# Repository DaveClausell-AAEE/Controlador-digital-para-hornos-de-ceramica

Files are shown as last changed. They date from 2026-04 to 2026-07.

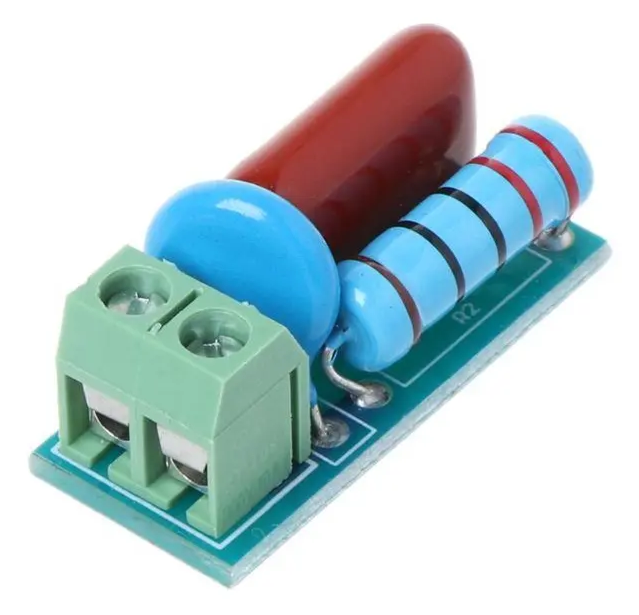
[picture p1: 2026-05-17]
hardware/snubber/snubber2.png

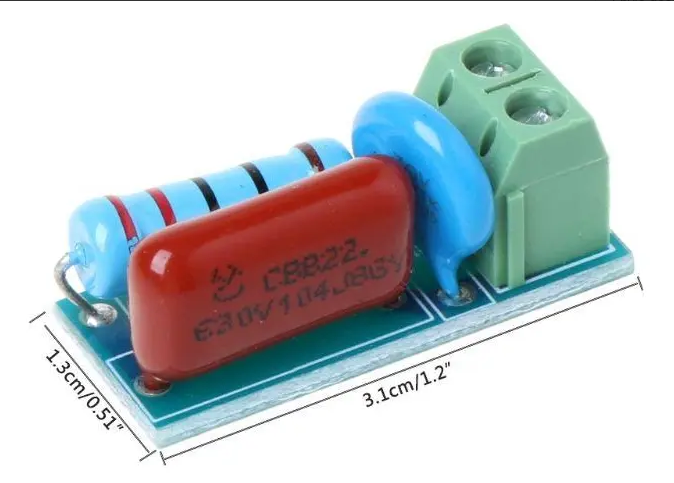
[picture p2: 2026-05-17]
hardware/snubber/snubber1.png

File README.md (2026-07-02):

# Controlador Digital para Horno de Cerámica (ESP32) V13.0 Industrial

Este proyecto es un controlador de temperatura profesional para hornos de cerámica basado en el microcontrolador **ESP32**. La versión 13.0 introduce una arquitectura de grado industrial con buses de datos separados para máxima estabilidad y feedback visual remoto.

## 🚀 Características Principales (V13.0 Industrial)
- **Arquitectura SPI Dual:** Separación física de buses (HSPI para sensor, VSPI para pantalla) para eliminar ruidos e interferencias en lecturas críticas.
- **LED Status RGB:** Visualización rápida del estado desde lejos (Azul: Online, Amarillo: Calentando, Verde: Listo, Rojo: Fallo, Cian: Config).
- **Hard Reset por Software:** Reinicio seguro del equipo mediante combinación de botones (OK + EXIT por 3s).
- **Inmunidad al Ruido:** Configuración de pines para entornos industriales hostiles y recomendaciones de filtrado bypass.
- **WiFi Manager & Portal Cautivo:** Configuración de red inalámbrica sin tocar el código.
- **Servidor Web de Monitoreo:** Visualiza la temperatura y el estado en tiempo real.
- **Seguridad Industrial:** Watchdog térmico, Autorecovery y alarmas sonoras/visuales.

## 🛠️ Hardware y Pinout (V13.0 Industrial + Personality Module)
| Componente | Pin ESP32 | Función | Bus / Tipo |
|---|---|---|---|
| **Relé (Ext)** | GPIO 17 | Control Resistencia (Active LOW) | Digital |
| **Buzzer (Ext)**| GPIO 27 | Alarma y Feedback | Digital |
| **LED RGB (R)** | GPIO 16 | Estado (Rojo) | Digital |
| **LED RGB (G)** | GPIO 21 | Estado (Verde) | Digital |
| **LED RGB (B)** | GPIO 22 | Estado (Azul) | Digital |
| **Botón UP**| GPIO 36 (SVP) | Navegación | Input Only (Ext Pull-up) |
| **Botón DOWN**| GPIO 39 (SVN) | Navegación | Input Only (Ext Pull-up) |
| **Botón OK** | GPIO 34 | Confirmar / Editar | Input Only (Ext Pull-up) |
| **Botón EXIT**| GPIO 35 | Volver / Reset (Combo) | Input Only (Ext Pull-up) |
| **TFT LED** | GPIO 12 | Brillo Pantalla | PWM |
| **SD CS** | GPIO 33 | Selección Tarjeta SD | **VSPI** |
| **Sensor (K)** | SPI (HSPI) | MAX31855 (CLK: 14, MISO: 13, CS: 5) | **HSPI** |
| **Pantalla** | SPI (VSPI) | ILI9341 (SCK: 18, MISO: 19, MOSI: 23, CS: 15) | **VSPI** |

## 📶 Configuración WiFi
1. Si no hay red, busque la WiFi `HORNO-CONFIG` en su móvil.
2. IP de configuración: `192.168.4.1`.
3. Para borrar el WiFi: **Ajustes > Reset WiFi** o use el Hard Reset (OK+EXIT).

## 🛡️ Notas de Montaje Industrial
- **Filtrado:** Colocar un capacitor de 10uF y uno de 100nF entre VCC y GND de la ESP32.
- **Modularidad:** Mantener la fuente de 220V/5V y el relé de potencia fuera de la placa de control para minimizar interferencias.
- **Hard Reset:** Mantenga presionados OK y EXIT por 3 segundos para forzar un reinicio del sistema.

## 🧪 Metodología de Pruebas (Pre-Instalación)
Antes de conectar a un horno real, se recomienda realizar las pruebas detalladas en el manual de validación técnica (ver sección de testing).

---
Desarrollado por **DAC LAB**

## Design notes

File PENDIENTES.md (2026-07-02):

# 📝 Tareas Pendientes - Controlador Horno V13.0

## 🛠️ Hardware (Validado ✅)
- [x] Soldar resistencias de 10k (Pull-up) a 3.3V para los botones.
- [x] Mover botones a los nuevos pines:
    - UP -> GPIO 36 (SVP)
    - DOWN -> GPIO 39 (SVN)
    - OK -> GPIO 34
    - EXIT -> GPIO 35
- [x] Conectar Pin CS de la SD al GPIO 33.
- [ ] **Circuito Snubber (Protección Inductiva):** 
    - Instalar el módulo comercial (RC + Varistor) visto en `hardware/snubber/`.
    - Conectar en paralelo con la bobina del contactor.

## 🧪 Pruebas y Validación
- [x] Ejecutar `Diagnostic_SD_Buttons_V13.ino` para validar el nuevo hardware.
- [x] Verificar que la pantalla no presente parpadeos al usar la SD simultáneamente.

## 💻 Software / Firmware (Hacia V14.0)
- [x] Migrar lógica de `CC_V13.0.ino` a `CC_V14.0.ino`.
- [x] Implementar la lógica de "Personality Module" (Sincronización LittleFS <-> SD).
- [x] Integrar feedback visual en LED RGB (Azul: Standby, Naranja: Calentando, Verde: Fin, Rojo: Error).
- [x] Añadir aviso visual en la barra de estado si la SD no está presente.

---
*Referencia técnica: Ver `GEMINI.md` para mandatos de arquitectura.*

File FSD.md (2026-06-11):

# Documento de Especificaciones Funcionales (FSD) - Controlador de Horno de Cerámica

## 1. Descripción General
Este proyecto consiste en un sistema de control de temperatura de alta precisión basado en el microcontrolador **ESP32**, diseñado específicamente para hornos de cerámica que requieren curvas de temperatura complejas (rampas y mantenimientos). El sistema utiliza un algoritmo **PID** para gestionar la potencia del horno a través de un relé de estado sólido o electromecánico.

## 2. Hardware del Sistema
- **Microcontrolador:** ESP32 (38-pin Dev Module).
- **Sensor de Temperatura:** Módulo MAX31855 con Termocupla Tipo K (Rango hasta 1350°C).
- **Actuador:** Relé de potencia (Configuración Active-LOW).
- **Interfaz Visual:** Pantalla TFT ILI9341 (320x240 px) con controlador SPI.
- **Entradas de Usuario:** 4 Pulsadores (UP, DOWN, OK, EXIT).

## 3. Pinout Detallado (Arquitectura Industrial V13.0 + Personality Module)

```text
       ESP32 (38-pin Dev Module) - Conexión Directa a TFT
      +-------------------------------------------+
      | [GND] [5V] [3.3V] ...                     |
(D12) | TFT_LED (PWM)      GPIO 17 [EXT] -> RELAY |
(D14) | SENSOR_CLK (HSPI)  GPIO 27 [EXT] -> BUZZER|
(D13) | SENSOR_MISO(HSPI)  GPIO 33 [OUT] -> SD_CS |
(D5 ) | SENSOR_CS  (HSPI)  GPIO 34 [IN]  <- BTN_OK|
      |                    GPIO 35 [IN]  <- BTN_EX|
(D16) | LED_RED            GPIO 36 (SVP) [IN]  <- BTN_UP|
(D21) | LED_GREEN          GPIO 39 (SVN) [IN]  <- BTN_DN|
(D22) | LED_BLUE           SPI (VSPI para TFT/SD) |
      |                    SCK: 18, MISO: 19      |
(D2 ) | TFT_DC             MOSI: 23, CS: 15       |
(D4 ) | TFT_RST                                   |
      +-------------------------------------------+

Nota: Los botones (34-39) requieren Pull-up externo a 3.3V.
```

| Componente | Pin ESP32 | Función | Bus / Tipo |
|---|---|---|---|
| **Relé (Externo)** | GPIO 17 | Control de Resistencia | Digital (Active LOW) |
| **Buzzer (Ext)** | GPIO 27 | Alarma Sonora | Digital |
| **LED RGB (R)** | GPIO 16 | Estado (Rojo) | Digital |
| **LED RGB (G)** | GPIO 21 | Estado (Verde) | Digital |
| **LED RGB (B)** | GPIO 22 | Estado (Azul) | Digital |
| **Botón UP** | GPIO 36 (SVP) | Navegación | Input Only (Ext Pull-up) |
| **Botón DOWN** | GPIO 39 (SVN) | Navegación | Input Only (Ext Pull-up) |
| **Botón OK** | GPIO 34 | Confirmar | Input Only (Ext Pull-up) |
| **Botón EXIT** | GPIO 35 | Volver | Input Only (Ext Pull-up) |
| **TFT LED** | GPIO 12 | Brillo Pantalla | PWM |
| **TFT CS** | GPIO 15 | Selección TFT | **VSPI** |
| **SD CS** | GPIO 33 | Selección SD | **VSPI** |
| **MAX31855 CLK**| GPIO 14 | Reloj Sensor | **HSPI** |
| **MAX31855 MISO**| GPIO 13 | Datos Sensor | **HSPI** |
| **MAX31855 CS** | GPIO 5 | Selección Sensor | **HSPI** |

## 4. Recomendaciones de Ingeniería Industrial (V13.0)
### 4.1 Integridad de Señal y Ruido
- **Separación de Buses SPI:** Se utiliza HSPI para el sensor de temperatura y VSPI para la pantalla TFT. Esto evita interferencias electromagnéticas (EMI) y cuellos de botella en el bus compartidos que podrían corromper las lecturas críticas del MAX31855.
- **Filtrado de Alimentación:** Implementar un filtro pasa-banda en la entrada de 3.3V del ESP32 con un capacitor electrolítico de 10uF (baja frecuencia) y uno cerámico de 100nF (alta frecuencia) lo más cerca posible de los pines de alimentación.
- **Aislamiento de Pines:** Todos los pines GPIO no utilizados deben configurarse explícitamente como `INPUT_PULLUP` o `OUTPUT` en estado bajo para evitar que actúen como antenas de ruido.

### 4.2 Diseño Físico y Modularidad
- **Modularidad de Potencia:** La fuente de alimentación y el relé deben ubicarse en un módulo externo separado. La placa de control solo recibe alimentación DC limpia y envía señales de control de bajo nivel.
- **Factor de Forma:** Placa compacta diseñada para encajar directamente en los pines traseros de una pantalla ILI9341, optimizando el espacio y reduciendo el cableado.

### 4.3 Interfaz de Usuario Remota (LED de Estado)
- **AZUL:** Conectado a WiFi, en espera (Stand-by).
- **NARANJA/AMARILLO:** Horneado en curso (Calentando).
- **VERDE:** Ciclo terminado / Manteniendo.
- **ROJO:** Error crítico / Fallo de sensor.
- **CIAN PARPADEANTE:** Modo Configuración (Punto de Acceso).

### 4.4 Funciones de Recuperación
- **Hard Reset:** Presionar simultáneamente **OK + EXIT** durante 3 segundos provocará un reinicio de software (`ESP.restart()`).

## 4. Funcionalidades Principales
### 4.1 Gestión de Programas
- Soporte para hasta **5 programas** distintos en memoria.
- Cada programa consta de hasta **10 etapas** configurables.
- Parámetros por etapa:
  - **Rampa:** Velocidad de ascenso/descenso (°C por hora).
  - **Temperatura Meta:** Punto final de la etapa (°C).
  - **Tiempo de Mantenimiento:** Duración de la temperatura una vez alcanzada (minutos).

### 4.2 Control de Temperatura (PID)
- Algoritmo PID para evitar sobre-oscilaciones.
- Ventana de control de tiempo (Time Proportioning Control) de 5 segundos.
- Modo simulación acelerada (x60) para pruebas de lógica.

### 4.3 Menú de Calibración
- Ajuste de **Offset** en tiempo real para corregir desviaciones de la termocupla.
- Visualización de temperatura cruda vs temperatura corregida.

### 4.4 Personalización y UI Avanzada
- **Control de Brillo:** Ajuste de intensidad lumínica desde el menú de ajustes (PWM).
- **Splash Screen:** Pantalla de bienvenida `"Controlador by DAC LAB"` con animación de carga al iniciar.
- **Barra de Estado Proactiva:** Muestra la temperatura y el estado actual del horno (LISTO, CALENT., etc.) de forma persistente.
- **Info Sistema:** Medidor visual del porcentaje de ocupación de la memoria LittleFS.

### 4.5 Ajustes PID Dinámicos
- Menú interactivo para modificar los parámetros Kp, Ki y Kd sin necesidad de modificar el código fuente.

## 5. Casos de Prueba y Manejo de Errores

| Caso de Prueba | Acción del Sistema | Estado de Seguridad |
|---|---|---|
| **Falla del Sensor (MAX31855)** | Si el sensor devuelve `NaN` o error de conexión, se detiene el ciclo de horneado inmediatamente. | **Relé OFF (HIGH)** |
| **Sobre-temperatura** | Si la temperatura supera el límite de seguridad (ej. 1200°C), se activa la alarma y se corta el relé. | **Relé OFF (HIGH)** |
| **Desconexión de Relé** | El sistema detecta si no hay cambio de temperatura tras 10 min de activación (Watchdog térmico). | **Estado de FALLO** |
| **Pérdida de Energía** | Al reiniciar, el horno consulta `/recovery.bin` para intentar retomar el ciclo donde quedó. | **AUTORECOVERY** |
| **Error de Etapa** | Si una rampa es imposible de alcanzar por el hardware, el sistema notificará pero mantendrá el control PID al máximo. | **ACTIVO** |

## 6. Estructura del Proyecto
- **/versiones/**: Repositorio histórico de las versiones del firmware (.ino).
- **/Diagnostic_Hardware/**: Scripts de prueba para verificar el funcionamiento de la pantalla, sensor y relé.
- **FSD.md**: Especificaciones funcionales y técnicas del sistema.
- **CHANGELOG.md**: Registro histórico de cambios y mejoras implementadas.
- **README.md**: Documentación de hardware y guía rápida de configuración.

## 7. Estado del Desarrollo y Próximos Pasos
### 7.1 Hitos Completados ✅
- Implementación de la librería `Adafruit_MAX31855` para lecturas reales del sensor.
- Persistencia de datos mediante `LittleFS` para guardar programas, calibración, PID y brillo.
- Sistema de edición visual completo para programas y etapas.
- Gráfica de temperatura en tiempo real con escalado dinámico y etiquetas de tiempo.
- **Auto-recovery:** Guardado de estado dinámico en LittleFS.
- **Alarmas Sonoras:** Integración completa de buzzer con sonidos diferenciados.
- **Conectividad WiFi:** Servidor web integrado para monitoreo remoto y pantalla de info sistema con IP.

### 7.2 Próximos Pasos 🚀
1. **Seguridad Avanzada:** Implementar un sistema de notificaciones por email/telegram en caso de fallo.
2. **Histórico de Horneados:** Guardar un log de los últimos horneados en LittleFS para descargar vía web.
onidos diferenciados.
- **Conectividad WiFi:** Servidor web integrado para monitoreo remoto y pantalla de info sistema con IP.

### 7.2 Próximos Pasos 🚀
1. **Seguridad Avanzada:** Implementar un sistema de notificaciones por email/telegram en caso de fallo.
2. **Histórico de Horneados:** Guardar un log de los últimos horneados en LittleFS para descargar vía web.
gar vía web.

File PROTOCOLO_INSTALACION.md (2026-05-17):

# 📋 Protocolo de Instalación y Puesta en Marcha (V13.0)

Este protocolo asegura que el controlador pase del banco de pruebas al horno real sin fallos críticos. Sigue los pasos en orden estricto.

## Fase 1: Verificación Eléctrica (Sin ESP32 conectado)
*Objetivo: Proteger el microcontrolador de picos de tensión.*

1.  **Fuente de Alimentación:** Conecta la fuente 220V/5V. Mide con multímetro la salida: debe ser **5V (+/- 0.2V)** constantes.
2.  **Continuidad de GND:** Verifica que todos los puntos de tierra (botones, pantalla, relé, sensor) compartan el mismo negativo.
3.  **Seguridad del Relé:** Verifica que sin señal del ESP32, el relé de potencia esté **ABIERTO** (horno apagado).

## Fase 2: Montaje y Sensores
1.  **Instalar ESP32:** Inserta el módulo y carga el firmware.
2.  **Conexión de Termocupla:** Conecta los cables de la sonda al MAX31855. 
    *   *Nota:* Si la temperatura baja al calentar la punta, invierte los cables de la sonda.
3.  **Buzzer y LED:** Confirma que al encender, el LED se ponga Azul (Stand-by) y el buzzer emita dos pitidos cortos.

## Fase 3: Calibración de Temperatura (Puntos de Referencia)
*Usar el termómetro físico de vidrio como patrón. El horno tiene un offset ajustable en Menú > Ajustes > Calibración.*

1.  **Punto Cero (Hielo):** 
    *   Sumerge la punta de la sonda y el termómetro de vidrio en un vaso con hielo picado y un poco de agua.
    *   Espera 2 minutos a que estabilice.
    *   Anota la diferencia. Si el controlador marca 2°C y el de vidrio 0.5°C, el offset inicial es de -1.5°C.
2.  **Punto Ebullición (Agua Hirviendo):**
    *   Sumerge ambos en agua hirviendo. 
    *   Ajusta el **Offset** en el menú hasta que la lectura del controlador coincida con el termómetro de vidrio (aprox 100°C dependiendo de la altitud).
3.  **Verificación de Ambiente:** Deja que la sonda vuelva a temperatura ambiente. Debe marcar lo mismo que el termómetro de vidrio en reposo.

## Fase 4: Prueba de Carga (Simulada y Real)
1.  **Simulación de Relé:** Sin conectar el horno a 220V, inicia un programa. Escucha el "click" del relé o observa su LED indicador.
2.  **Watchdog Térmico:** Inicia el calentamiento real. Verifica que en los primeros 10 minutos la temperatura suba consistentemente. Si no sube, el sistema debe entrar en **FALLO** automáticamente por seguridad.

## Fase 5: Backup Final
1.  Una vez calibrado y configurado el WiFi, inserta la tarjeta SD.
2.  Entra en ajustes y fuerza un guardado para que se cree el `config.bin` de backup.
3.  **Prueba de Fuego:** Apaga el equipo, quita el ESP32, pon uno nuevo, inserta la SD y enciende. El nuevo módulo debe heredar toda la configuración automáticamente.

---
*Si algún paso falla, NO procedas al siguiente. Consulta el `FSD.md` o el `GEMINI.md` para diagnóstico.*

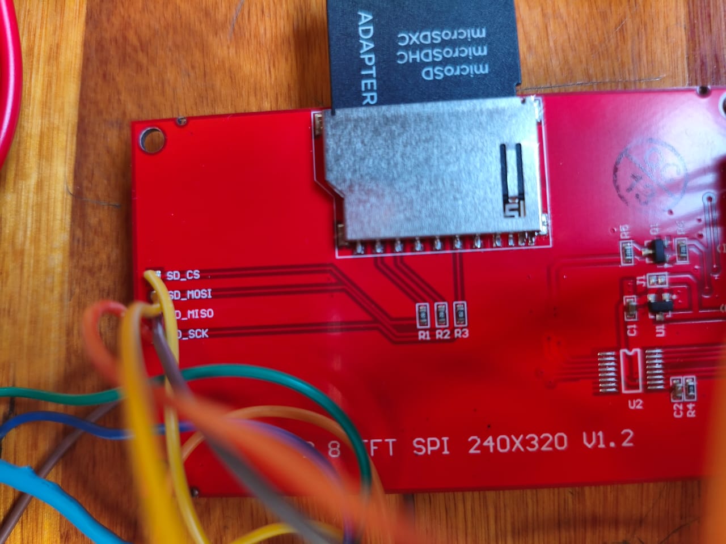
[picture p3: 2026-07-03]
Diagnostic_Hardware/SD.jpeg

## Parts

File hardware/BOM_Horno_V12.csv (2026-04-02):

Componente | Descripción | Referencia/Modelo | Cantidad | Notas
Microcontrolador | ESP32 38-Pin Dev Module | ESP32-WROOM-32 | 1 | Versión 38 pines (no 30)
Pantalla TFT | Pantalla Color SPI 2.4" | ILI9341 240x320 | 1 | Sin Touch (más barata)
Módulo Sensor | Conversor Termocupla SPI | MAX31855 | 1 | Incluye bornera para tipo K
Fuente de Poder | AC-DC 5V/3W | HLK-PM01 | 1 | Montaje en PCB (aislado)
Fusible | Portafusible + Fusible 1A | 5x20mm Glass Fuse | 1 | Seguridad entrada 220V
Varistor | Protección contra picos AC | 10D471K | 1 | Conectar en paralelo a entrada AC
Buzzer | Zumbador Activo 5V | Active Buzzer 5V | 1 | Sonido continuo al aplicar voltaje
Relé Externo | Relé de Estado Sólido (SSR) | SSR-25DA (25A) | 1 | Montar fuera de la placa con disipador
Termocupla | Sensor de Alta Temperatura | Tipo K (Blindada) | 1 | Rango hasta 1250°C
Borneras | Conector de tornillo 5.08mm | KF301-2P | 3 | AC IN, SSR OUT, Termocupla
Pulsadores | Botón táctil PCB | 6x6x5mm Tact Switch | 4 | Navegación del menú
Tira de Pines (Zócalos) | Conector Hembra 2.54mm | Female Header 1x19 (2 uds) | 1 | Para pinchar el ESP32
Tira de Pines (Módulos) | Conector Hembra 2.54mm | Female Header 1x14 | 1 | Para la pantalla TFT
Capacitores | Filtrado de ruido botones | 100nF Ceramic | 4 | Opcional pero recomendado
Resistencias | Limitación corriente LED | 220 Ohm 1/4W | 1 | Para el backlight de la pantalla
PCB Custom | Placa de circuito impreso | FR4 2-Layer 10x10cm | 1 | Manda a fabricar en JLCPCB

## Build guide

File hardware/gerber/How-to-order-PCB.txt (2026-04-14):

How to Order PCB

Please refer to:
https://prodocs.easyeda.com/en/pcb/order-order-pcb/index.html

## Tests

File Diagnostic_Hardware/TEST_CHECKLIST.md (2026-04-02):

# 📋 Checklist de Validación Técnica - Controlador V12.2

Este documento sirve de guía para validar el funcionamiento del controlador de horno antes de su instalación definitiva en el hardware de potencia.

### 1. Verificación de Interfaz y Sonido
- [ ] **Splash Screen:** ¿Aparece el logo "Controlador by DAC LAB" al encender?
- [ ] **Pitidos de Inicio:** ¿Suena el doble pitido corto al arrancar?
- [ ] **Navegación:** ¿Cada pulsación de botón genera un "click" audible?
- [ ] **Visibilidad:** ¿El menú de Ajustes se ve completo (6 ítems) sin cortarse abajo?
- [ ] **Configuración de Sonido:** Entra en Ajustes > Sonido. Cámbialo a "NO". ¿Se silencian los clicks? ¿Se mantienen silenciados tras reiniciar el equipo?

### 2. WiFi y Conectividad (Modo AP)
- [ ] **Modo Configuración:** Ve a Ajustes > Reset WiFi. ¿Aparece la pantalla de ayuda con la red `HORNO-CONFIG` y la IP `192.168.4.1`?
- [ ] **Portal Cautivo:** Conéctate con tu móvil a `HORNO-CONFIG`. ¿Carga la página de configuración al entrar a la IP?
- [ ] **Conexión Real:** Introduce tus credenciales reales. ¿El horno se reinicia y muestra una IP válida en "Info Sistema"?
- [ ] **Monitoreo Web:** Entra a la IP del horno desde tu móvil. ¿Ves la temperatura en tiempo real en el navegador?

### 3. Lógica de Control y Gráfica (Simulación)
- [ ] **Inicio de Programa:** Selecciona un programa y dale a "Iniciar". ¿Muestra el resumen antes de empezar?
- [ ] **Gráfica Dinámica:** Deja que el programa corra unos minutos. ¿Aparecen los puntos en la gráfica? ¿Son visibles las etiquetas "-10m" y "Ahora" en la base?
- [ ] **Escalado de Eje Y:** Durante la simulación, ¿el número máximo del eje Y de la gráfica aumenta automáticamente?
- [ ] **Control de Relé:** Verifica el LED del Relé (pin 17). ¿Parpadea según la salida del PID? (Debería estar más tiempo encendido al principio y parpadear más al acercarse al setpoint).

### 4. Seguridad y Fallos
- [ ] **Fallo de Sensor:** Con el programa corriendo, desconecta la termocupla. ¿Se detiene el proceso y muestra una pantalla de error roja? ¿El relé se apaga inmediatamente?
- [ ] **Auto-Recovery:** Apaga el equipo en medio de un horneado simulado. Al encenderlo, ¿te pregunta si quieres retomar el ciclo?
- [ ] **Buzzer de Alarma:** En caso de error o fin de ciclo, ¿los sonidos son claramente diferentes a los clicks normales?

---
*Manual de pruebas generado por DAC LAB - 2026*

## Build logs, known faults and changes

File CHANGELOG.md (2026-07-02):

# Historial de Versiones - Controlador de Horno

Este archivo registra la evolución del software, las nuevas funcionalidades y las correcciones implementadas en cada versión.

---

## [14.0] - 2026-07-02 (Actual)
### 💾 Personality Module & Dual Persistence Sincronizada
- **Persistencia Dual (Mirroring):**
    - Sincronización en tiempo real de `config.bin` entre LittleFS y la tarjeta SD.
    - Los cambios en programas, calibración, brillo, PID y sonido se escriben simultáneamente en ambos medios.
- **Personality Module (Restauración Bidireccional):**
    - Al inicio, si LittleFS está vacío pero hay una tarjeta SD, se clona la configuración desde la SD de forma automática.
    - Si existe configuración en LittleFS pero no en la SD (tarjeta nueva), se genera un backup inicial en la SD automáticamente.
    - Permite el reemplazo directo y rápido de módulos ESP32 en campo sin pérdida de datos del horno.
- **Aviso Visual de SD:**
    - Indicador de estado en la esquina superior derecha de la barra de estado de la pantalla TFT: muestra `SD` en verde si está correctamente montada o `NO SD` en rojo si falta o falló la tarjeta.
- **Feedback Visual RGB:**
    - Se actualizó el LED de estado para que muestre de forma persistente color **Azul** en standby/menús, **Naranja** al calentar, **Verde** al finalizar/mantener y **Rojo** en caso de fallo.

## [13.0] - 2026-06-11
### ✅ Hito: Validación de Hardware V13.0 Completa
- **Arquitectura:** Validado el nuevo pinout industrial (Botones en 34-39, SD en 33).
- **Pantalla:** Control de backlight (GPIO 12) implementado y verificado.
- **SD Card:** Corregida inestabilidad del bus SPI mediante reducción de frecuencia a 4MHz y gestión de CS.
- **Periféricos:** Verificado funcionamiento de Relé (Active-LOW), Buzzer y LED RGB.
- **Diagnóstico:** Creado `Diagnostic_V13_Full` como herramienta de referencia para soporte técnico.

## [13.0] - 2026-04-14
### 🏗️ Arquitectura de Grado Industrial
- **Dual SPI Bus:**
    - Implementada separación física de buses: **HSPI** exclusivo para el sensor MAX31855 y **VSPI** para la pantalla TFT.
    - Reduce drásticamente el ruido electromagnético en las lecturas de temperatura.
- **Feedback Visual de Estado (LED RGB):**
    - Añadida lógica para LED RGB en GPIOs 16, 21 y 22.
    - Colores: **Azul** (Online), **Amarillo** (Horneando), **Verde** (Listo/Mantenimiento), **Rojo** (Fallo), **Cian parpadeante** (Modo AP).
- **Hard Reset por Software:**
    - Nueva función de reinicio de emergencia: Presionando **OK + EXIT por 3 segundos** se fuerza un `ESP.restart()`.
- **Integridad y Seguridad:**
    - Configuración de pines no usados en modo `INPUT_PULLUP` para evitar ruido tipo "antena".
    - Recomendaciones de filtrado (10uF + 100nF) añadidas a la documentación.
- **Diseño Modular:**
    - El código ahora asume relé y fuente externos para mayor limpieza eléctrica.

---

## [V12.2] - 2026-04-01
### 🐛 Corrección de Interfaz de Inicio
- **Fix Pantalla Standby:**
    - Corregido error por el cual las etiquetas de "Temp. Actual" y "Programa Listo" no aparecían inmediatamente tras la pantalla de bienvenida.
    - Se forzó el dibujado completo del layout al iniciar el sistema.
- **Estabilidad Visual:**
    - Mejorada la gestión de estados para garantizar refrescos completos en el primer ciclo.

---

## [V12.1] - 2026-04-01
### 🎨 UI Optimizada y Guía de Configuración
- **Mejora en Modo AP:**
    - Ahora la pantalla TFT muestra instrucciones claras cuando el horno está en modo configuración.
    - Se indica la red WiFi (`HORNO-CONFIG`) y la dirección IP (`192.168.4.1`) directamente en el display.
- **Ajuste de Gráfica:**
    - La base de la gráfica se ha subido 10 píxeles para garantizar que las etiquetas de tiempo ("-10m" y "Ahora") sean completamente visibles.
- **Estabilidad de WiFi:**
    - Corregida lógica de reconexión en el loop principal.

---

## [V12.0] - 2026-04-01
### 📶 WiFi Manager y Configuración Dinámica
- **Modo Punto de Acceso (AP):**
    - Si no hay WiFi configurado o falla la conexión, el horno crea su propia red `HORNO-CONFIG`.
    - Permite configurar el SSID y Password desde un portal cautivo en el móvil (`192.168.4.1`).
- **Persistencia de Red:**
    - Las credenciales se guardan de forma segura en `/wifi.bin` dentro de LittleFS.
- **Opción de Reset WiFi:**
    - Añadida función en **Ajustes > Reset WiFi** para borrar las credenciales y forzar el modo configuración.
- **Interfaz Informativa:**
    - La pantalla de Info WiFi ahora indica explícitamente cuando el dispositivo está en modo `CONFIG AP`.

---

## [V11.1] - 2026-04-01
### 🔊 Feedback Sonoro y Ajustes de Usuario
- **Sonidos de Interfaz:**
    - Implementado un sonido de "click" (20ms) al navegar por los menús y pulsar botones.
    - Mejora la experiencia táctil y confirma las acciones del usuario.
- **Gestión de Sonido:**
    - Nueva opción en el menú de **Ajustes > Sonido** para habilitar o deshabilitar los pitidos.
    - El estado del sonido se guarda de forma persistente en LittleFS.
- **Correcciones Técnicas:**
    - Optimización del orden de declaración de variables globales.

---

## [V11.0] - 2026-04-01
### 🌐 Conectividad y Monitoreo Remoto
- **Implementación de WiFi:**
    - Conexión automática a red WiFi configurada.
    - Sistema de reconexión automática en el loop.
- **Servidor Web Básico:**
    - Servidor HTTP integrado que permite ver el estado y la temperatura en tiempo real desde cualquier dispositivo en la red.
    - Refresco automático de la página cada 5 segundos.
- **Mejora en Info Sistema:**
    - La pantalla de información ahora muestra la dirección IP local si está conectado, o "DESC." si no lo está.
    - Reorganización visual de los datos de memoria y programas.
- **Optimización de Gráfica en Tiempo Real:**
    - Implementado escalado dinámico del eje Y según la temperatura máxima registrada (con margen del 10%).
    - Añadidas etiquetas de escala de temperatura (0 a Max).
    - Añadidas etiquetas de tiempo en el eje X ("-10m" y "Ahora") para mejor legibilidad.

---

## [V10.9] - 2026-03-26
### 🚀 Nuevas Funcionalidades y Personalización
- **Personalización de Bienvenida:** Nueva Splash Screen con el texto `"Controlador by DAC LAB"` y animación de carga.
- **Control de Brillo por Software:**
    - Añadida opción en el menú de Ajustes para regular la intensidad de la pantalla (PWM en GPIO 12).
    - El nivel de brillo se persiste automáticamente en LittleFS.
- **Gestión de Memoria Visual:** Nuevo apartado en **Info Sistema** que muestra el porcentaje de uso de LittleFS.
- **Ajustes PID en Vivo:** Menú dedicado para modificar Kp, Ki y Kd desde la interfaz sin necesidad de reprogramar.
- **Status Bar Informativo:** La barra superior ahora muestra el estado del horno (LISTO, CALENT., MANTEN., etc.) de forma persistente.
- **Traducción de Estados:** Cambio de "IDLE" a "LISTO" para una interfaz más intuitiva en español.

---

## [V10.8] - 2026-03-25
### 🛡️ Seguridad y Sonido
- **Sistema de Auto-Recuperación:** Implementado guardado de estado en `/recovery.bin` para retomar el horneado tras un fallo de energía.
- **Integración de Buzzer:**
    - Sonidos diferenciados para: Inicio de sistema (doble pitido corto), Fin de ciclo (pitido largo) y Fallo (triple pitido de alerta).
- **Herramienta de Diagnóstico V1.1:** Actualizada para incluir pruebas de sonido y corregir el pinout del buzzer (GPIO 27).

---

## [V10.7] - 2026-03-25
### 🎨 Mejoras de Interfaz y Correcciones
- **Corrección de Menú de Calibración:** Se ajustó la lógica para evitar actualizaciones si el sensor no está disponible y mejorar la experiencia de edición del offset.
- **Corrección de Tipografía:** Reemplazo de "ñ" por "n" en etiquetas de menú para garantizar compatibilidad con el set de caracteres del display.
- **Optimización de Refresco:** Se mejoró el refresco de pantalla en los menús de configuración para eliminar artefactos visuales y texto remanente.
- **Layout de Pantalla:** Se ajustó el layout de la pantalla de "Calentando/Manteniendo" para evitar la superposición de texto y números de temperatura.
- **Estabilidad de Lectura:** Se optimizó el refresco de la temperatura en la barra superior para evitar parpadeos innecesarios.

---

## [V10.6] - 2026-03-24
### 📊 Visualización Avanzada y UX
- **Gráfica de Temperatura en Tiempo Real:**
    - Se añadió un área de visualización gráfica durante el horneado.
    - Muestra los últimos 10 minutos de historia térmica (muestreo cada 5s).
- **Pantalla de Confirmación Pre-Vuelo:**
    - Nuevo estado de seguridad que muestra un resumen del programa (Nombre, Etapas, Temp. Máxima) antes de iniciar el calentamiento.
- **Diagnóstico de Errores Mejorado:**
    - El Watchdog Térmico ahora muestra mensajes específicos como: `"SIN AUMENTO DE TEMP: REVISAR RESISTENCIA"`.
- **Menú de Información WiFi:**
    - Nueva pantalla en Ajustes que muestra la dirección MAC del dispositivo, facilitando su identificación para futuras funciones de red.
- **Optimización de Interfaz:**
    - Ajuste de diseño en la pantalla de horneado para dar espacio a la gráfica sin perder legibilidad en los datos numéricos.

---

## [V10.5] - 2026-03-24
### 🛠️ Herramientas de Edición y Seguridad
- **Edición de Nombres "In-Situ":**
    - Implementado sistema de edición de caracteres letra por letra con parpadeo visual.
    - Navegación circular entre caracteres (A-Z, espacio, 0-9).
- **Gestión Dinámica de Etapas:**
    - Añadidas funciones para **Añadir Etapa** (hasta 10) y **Borrar Etapa** (mínimo 1) desde el menú de configuración.
    - Los cambios se guardan automáticamente en LittleFS.
- **Seguridad: Watchdog Térmico:**
    - Nuevo sistema de seguridad que monitorea la eficacia del calentamiento.
    - Si el relé está activo pero la temperatura no sube al menos 2°C en 10 minutos, el sistema corta la energía y muestra una pantalla de **FALLO** roja.
- **Mejoras Visuales:**
    - Implementado parpadeo (blink) en cursores de edición y selección de parámetros para mejorar el feedback al usuario.

---

## [V10.4] - 2026-03-24
### 💾 Persistencia y Gestión de Memoria
- **Implementación de LittleFS:**
    - Se añadió soporte para el sistema de archivos de memoria flash del ESP32.
    - Los programas y el ajuste de calibración ahora se guardan en un archivo binario `/config.bin`.
- **Persistencia Automática:**
    - Los datos se guardan automáticamente al salir del menú de edición de programas o al confirmar una calibración.
- **Mejora en Gestión de Programas:**
    - Se habilitó la funcionalidad de **"+ Crear Programa"**, permitiendo añadir nuevos programas vacíos directamente desde la interfaz.
    - Se cargan automáticamente datos de prueba en el primer inicio si no existe configuración previa.

---

## [V10.3] - 2026-03-24
### ✨ Mejoras en Hardware e Interfaz
- **Integración del Sensor MAX31855:**
    - Soporte nativo para lectura de Termocupla Tipo K mediante SPI (Pines compartidos con TFT).
    - Implementación de **Modo Híbrido**: Si el sensor falla o devuelve `NaN`, el sistema cambia automáticamente a **Modo Simulación** para permitir pruebas de UI sin hardware.
- **Interfaz de Configuración de Programas (UI):**
    - Se completó la visualización de parámetros por etapa (Rampa, Temperatura Meta, Tiempo).
    - Implementado sistema de resaltado visual (Amarillo) para indicar qué parámetro se está editando.
    - Navegación horizontal mejorada para ajustar valores con los botones UP/DOWN.
- **Barra de Estado Proactiva:**
    - La temperatura en la barra superior ahora se refresca en tiempo real en todos los menús, no solo en la pantalla principal.

---

## [V10.2] - Versión Base
### 📦 Funcionalidades Iniciales
- **Núcleo del Sistema:** Lógica de estados (Stand-by, Menú, Horneado).
- **Control PID:** Algoritmo básico de control de temperatura (simulado).
- **Menú de Calibración:** Ajuste de offset para la termocupla.
- **Interfaz Gráfica:** Menús básicos utilizando la librería `TFT_eSPI`.
- **Estructura de Datos:** Soporte para programas con múltiples etapas.

---

*Nota: Para volver a una versión anterior, simplemente carga el archivo `.ino` correspondiente a la versión deseada.*

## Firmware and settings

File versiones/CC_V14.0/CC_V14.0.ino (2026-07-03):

// =================================================================
// ==      CONTROLADOR DIGITAL PARA HORNO DE CERÁMICA V13.0       ==
// =================================================================
//      (Arquitectura Industrial, SPI Dual, LED Status, Hard Reset)
//

#include <SPI.h>
#include <TFT_eSPI.h> 
#include <PID_v1.h>
#include <Adafruit_MAX31855.h>
#include <LittleFS.h>
#include <SD.h>
using namespace fs;
#include <WiFi.h>
#include <WebServer.h>
#include <esp_mac.h>  // Para leer MAC desde eFuse directamente (ESP-IDF v5+)

// --- CONFIGURACIÓN SPI DUAL ---
// VSPI: SCK 18, MISO 19, MOSI 23, SS 15 (TFT) - Manejado por SPI global
// HSPI: SCK 14, MISO 13, MOSI 12 (NC), SS 5 (SENSOR)
SPIClass hspi(HSPI);

// --- PINOUT V13.0 ---
#define RELAY_PIN     17
#define BUZZER_PIN    27
#define LED_R_PIN     16
#define LED_G_PIN     21
#define LED_B_PIN     22
#define BTN_UP_PIN    36 // SVP
#define BTN_DOWN_PIN  39 // SVN
#define BTN_OK_PIN    34
#define BTN_EXIT_PIN  35
#define SD_CS         33 
#define TFT_LED       12 
#define MAXCS         5

// --- WiFi DYNAMICS ---
struct WiFiConfig { char ssid[32]; char pass[64]; bool configurado; };
WiFiConfig wConfig = {"", "", false};
WebServer server(80);
unsigned long lastWiFiCheck = 0;
bool wifiConectado = false;
bool modoAP = false;
bool sdInicializada = false;
const char* apSSID = "HORNO-CONFIG";

// --- SENSOR ---
Adafruit_MAX31855 thermocouple(MAXCS, &hspi);

// --- ESTRUCTURAS ---
#define MAX_ETAPAS 10
#define MAX_LARGO_NOMBRE 16
#define MAX_PROGRAMAS 5
#define STATUS_BAR_HEIGHT 30
#define GRAPH_POINTS 120 

struct Etapa { int rampa, temperatura, tiempo; };
struct Programa { char nombre[MAX_LARGO_NOMBRE]; Etapa etapas[MAX_ETAPAS]; int numEtapas; };

TFT_eSPI tft = TFT_eSPI(); 

// --- VARIABLES DE ESTADO ---
struct RecoveryData { int estadoActual; int etapaActualIndex; unsigned long tiempoInicioEtapa; };
Programa programas[MAX_PROGRAMAS];
int numProgramasGuardados = 0;
int programaActivoIndex = 0;
float currentTemperature = 25.0;
float prevTemperature = 0.0;
float temperaturaCrudaSimulada = 27.2; 
float calibracionOffset = 0.0;
bool sonidoHabilitado = true;

// Gráfica
float tempHistory[GRAPH_POINTS];
int graphIdx = 0;
unsigned long ultimoPuntoGrafo = 0;

enum EstadoHorno {
  STAND_BY, CALENTANDO, MANTENIENDO, ENFRIANDO, FALLO, 
  MENU_PRINCIPAL, MENU_SELECCION_PROG, MENU_CONFIG_PROG,
  MENU_AJUSTES, MENU_CALIBRACION, EDITANDO_NOMBRE,
  CONFIRMACION_INICIO, INFO_WIFI, MENU_AJUSTES_PID, MENU_AJUSTES_BRILLO
};
EstadoHorno estadoActual = STAND_BY;
EstadoHorno estadoPrevio = STAND_BY;

const char* errorMsgStr = "";
bool enModoEdicionHorizontal = false;
int menuPrincipalCursor = 0, menuAjustesCursor = 0, menuSeleccionProgCursor = 0;
int programaEnEdicionIndex = 0, configProgCursorVertical = 0, configProgCursorHorizontal = 0, charIndexEdicion = 0;
float valorCalibracionEditado = 0.0;

// Watchdog
unsigned long ultimoCheckWatchdog = 0;
float tempEnUltimoCheck = 0;
const unsigned long INTERVALO_WATCHDOG = 600000; 

unsigned long ultimoPulsoBoton = 0;
unsigned long comboResetStart = 0;
const long intervaloDebounce = 200;
bool necesitaRefresco = true;
bool parpadeoEstado = false;
unsigned long ultimoParpadeo = 0;

const char* menuPrincipalItems[] = {"Iniciar Programa", "Sel. Programa", "Ajustes"};
const char* menuAjustesItems[] = {"Info Sistema", "Calibracion", "Ajustes PID", "Brillo", "Sonido", "Reset WiFi"};
int brilloPantalla = 255;
int brilloRGB = 25; // Brillo por defecto de los LEDs RGB (10% de 255)
int menuPIDCursor = 0;

// --- PID ---
double pidSetpoint, pidInput, pidOutput;
double Kp=10, Ki=0.2, Kd=1; 
PID hornoPID(&pidInput, &pidOutput, &pidSetpoint, Kp, Ki, Kd, DIRECT);
unsigned long windowSize = 5000, windowStartTime;
int etapaActualIndex = 0;
unsigned long tiempoInicioEtapa = 0;
float tempInicioEtapa = 0;
unsigned long ultimoUpdateTempSimulada = 0;
const int SIM_MULTIPLIER = 60; 

// --- PROTOTIPOS ---
const char* getEstadoStr(EstadoHorno e);
void leerSensores();
void manejarPulsadores();
void procesarEntrada(bool, bool, bool, bool);
void ejecutarCicloDeHorneado();
void actualizarPantalla();
void dibujarBarraDeEstado();
void actualizarTemperaturaEnBarra();
void dibujarPantallaStandBy(bool);
void dibujarItemMenu(int, bool, const char*, int);
void dibujarMenuPrincipal(bool);
void dibujarMenuAjustes(bool);
void dibujarItemMenuSeleccion(int, bool);
void dibujarMenuSeleccionProg(bool);
void dibujarMenuConfigProg(bool);
void dibujarLineaDeEtapa(int);
void dibujarPantallaCalentando(bool);
void dibujarPantallaEnfriando(bool);
void dibujarPantallaCalibracion();
void dibujarPantallaFallo(const char*);
void dibujarPantallaConfirmacion();
void dibujarPantallaInfoWiFi();
void dibujarMenuPID(bool);
void dibujarMenuBrillo();
void dibujarPantallaBienvenida();
void dibujarGrafica();
void iniciarWiFi();
void iniciarModoAP();
void manejarRaizWeb();
void manejarConfigWiFi();
void guardarWiFiConfig();
void cargarWiFiConfig();
void borrarWiFiConfig();
String obtenerMACAddress(); // Lee MAC desde eFuse, sin depender del estado WiFi
void cargarProgramaDePrueba();
void guardarConfiguracion();
void cargarConfiguracion();
void actualizarLEDStatus();
void sonarClick();
void sonarBuzzer(int duracion, int veces = 1);

void setup() {
  Serial.begin(115200);
  
  // Configuración de Botones (Requieren Pull-up externo a 3.3V)
  pinMode(BTN_UP_PIN, INPUT);
  pinMode(BTN_DOWN_PIN, INPUT);
  pinMode(BTN_OK_PIN, INPUT);
  pinMode(BTN_EXIT_PIN, INPUT);
  
  // Pines de Salida
  pinMode(RELAY_PIN, OUTPUT);
  pinMode(BUZZER_PIN, OUTPUT);
  // Configuración de LED RGB con PWM para control de brillo
  ledcAttach(LED_R_PIN, 1000, 8);
  ledcAttach(LED_G_PIN, 1000, 8);
  ledcAttach(LED_B_PIN, 1000, 8);
  pinMode(SD_CS, OUTPUT);
  digitalWrite(SD_CS, HIGH);
  
  digitalWrite(RELAY_PIN, HIGH); // Off (Active Low)
  digitalWrite(BUZZER_PIN, LOW);
  
  // Aislamiento de pines no usados (Recomendación Industrial)
  int pinsNoUsados[] = {0, 25, 26, 32}; // Pines liberados en V14.0
  for(int p : pinsNoUsados) pinMode(p, INPUT_PULLUP);

  // Iniciar bus SPI global (VSPI) con pines explícitos para pantalla y SD
  SPI.begin(18, 19, 23, 15); // SCK, MISO, MOSI, SS (VSPI)

  // Iniciar bus HSPI para el sensor de temperatura (sin MOSI en pin 12 para evitar conflictos con PWM de pantalla)
  hspi.begin(14, 13, -1, 5); // SCK, MISO, MOSI(NC), SS (HSPI)

  if(!LittleFS.begin(true)) Serial.println("LittleFS error");

  // Iniciar pantalla TFT primero (inicializa el bus SPI global por defecto)
  tft.init(); 
  tft.setRotation(3);

  // Brillo Pantalla (PWM)
  ledcAttach(TFT_LED, 1000, 8); 
  cargarConfiguracion();
  ledcWrite(TFT_LED, brilloPantalla);
  
  dibujarPantallaBienvenida();

  // --- PERSONALITY MODULE ---
  // Iniciar SD en el bus SPI global compartido
  if(SD.begin(SD_CS)) {
    sdInicializada = true;
    Serial.println("SD Detectada y Montada. Verificando integridad...");
    verificarYClonarConfiguracionSD();
  } else {
    Serial.println("SD No Presente o Error al montar.");
  }
  
  if (!thermocouple.begin()) Serial.println("MAX31855 error");
  
  cargarEstadoRecuperacion(); 
  hornoPID.SetOutputLimits(0, windowSize);
  hornoPID.SetMode(AUTOMATIC);
  for(int i=0; i<GRAPH_POINTS; i++) tempHistory[i] = 0;

  tft.fillScreen(TFT_BLACK);
  estadoPrevio = (EstadoHorno)-1; 
  necesitaRefresco = true;
  
  iniciarWiFi();
  server.on("/", manejarRaizWeb);
  server.on("/save", manejarConfigWiFi);
  server.begin();
  
  actualizarLEDStatus();
  sonarBuzzer(100, 2);
}

void loop() {
  server.handleClient();
  
  // Gestión de WiFi y Reconexión
  if (millis() - lastWiFiCheck > 10000) {
    lastWiFiCheck = millis();
    if (WiFi.status() != WL_CONNECTED && !modoAP) {
      if (wifiConectado) { wifiConectado = false; WiFi.begin(wConfig.ssid, wConfig.pass); }
    } else if (WiFi.status() == WL_CONNECTED) {
      if (!wifiConectado) { wifiConectado = true; actualizarLEDStatus(); }
    }
  }

  leerSensores();
  manejarPulsadores();
  ejecutarCicloDeHorneado();
  
  // Parpadeo para UI y LED (si es necesario)
  if (millis() - ultimoParpadeo > 400) {
    ultimoParpadeo = millis(); 
    parpadeoEstado = !parpadeoEstado;
    if (estadoActual == EDITANDO_NOMBRE || enModoEdicionHorizontal || modoAP) necesitaRefresco = true;
    if (modoAP) actualizarLEDStatus(); // Hacer parpadear el LED en modo AP
  }
  
  // Actualizar historial de gráfica
  if ((estadoActual == CALENTANDO || estadoActual == MANTENIENDO) && (millis() - ultimoPuntoGrafo > 5000)) {
    ultimoPuntoGrafo = millis();
    tempHistory[graphIdx] = currentTemperature;
    graphIdx = (graphIdx + 1) % GRAPH_POINTS;
    necesitaRefresco = true;
  }
  
  actualizarPantalla();
}

// --- LÓGICA DE LED STATUS RGB ---
void setLEDColor(bool r, bool g, bool b) {
  ledcWrite(LED_R_PIN, r ? brilloRGB : 0);
  ledcWrite(LED_G_PIN, g ? brilloRGB : 0);
  ledcWrite(LED_B_PIN, b ? brilloRGB : 0);
}

void actualizarLEDStatus() {
  if (estadoActual == FALLO) { setLEDColor(1, 0, 0); return; } // ROJO
  if (modoAP) { setLEDColor(0, parpadeoEstado, parpadeoEstado); return; } // CIAN PARPADEO
  
  switch(estadoActual) {
    case CALENTANDO: setLEDColor(1, 1, 0); break; // AMARILLO/NARANJA
    case MANTENIENDO: setLEDColor(0, 1, 0); break; // VERDE
    case ENFRIANDO: setLEDColor(0, 1, 0); break; // VERDE
    case STAND_BY: setLEDColor(0, 0, 1); break; // AZUL (Standby)
    default: setLEDColor(0, 0, 1); break;
  }
}

void leerSensores() {
  double c = thermocouple.readCelsius();
  if (isnan(c)) {
    // Modo Simulación si falla sensor
    if (millis() - ultimoUpdateTempSimulada > 500) {
      ultimoUpdateTempSimulada = millis();
      if (digitalRead(RELAY_PIN) == LOW) temperaturaCrudaSimulada += 1.0;
      else if (temperaturaCrudaSimulada > 27.2) temperaturaCrudaSimulada -= 0.2;
      necesitaRefresco = true;
    }
    currentTemperature = temperaturaCrudaSimulada - calibracionOffset;
  } else {
    currentTemperature = c - calibracionOffset;
    temperaturaCrudaSimulada = c;
    if (abs(currentTemperature - prevTemperature) >= 0.5) { prevTemperature = currentTemperature; necesitaRefresco = true; }
  }
}

void manejarPulsadores() {
  bool u = digitalRead(BTN_UP_PIN) == LOW;
  bool d = digitalRead(BTN_DOWN_PIN) == LOW;
  bool o = digitalRead(BTN_OK_PIN) == LOW;
  bool e = digitalRead(BTN_EXIT_PIN) == LOW;

  // --- LÓGICA HARD RESET (OK + EXIT por 3s) ---
  if (o && e) {
    if (comboResetStart == 0) comboResetStart = millis();
    if (millis() - comboResetStart > 3000) {
      sonarBuzzer(100, 3);
      delay(500);
      ESP.restart();
    }
    return; // No procesar otras teclas si se mantiene el combo
  } else {
    comboResetStart = 0;
  }

  if (millis() - ultimoPulsoBoton < intervaloDebounce) return;
  if (u || d || o || e) { 
    ultimoPulsoBoton = millis(); 
    procesarEntrada(u, d, o, e); 
    necesitaRefresco = true; 
    actualizarLEDStatus();
  }
}

void procesarEntrada(bool subiendo, bool bajando, bool ok, bool exit) {
    if (subiendo || bajando || ok || exit) sonarClick();
    estadoPrevio = estadoActual;
    switch (estadoActual) {
      case STAND_BY: if (ok) estadoActual = MENU_PRINCIPAL; break;
      case MENU_PRINCIPAL:
        if (subiendo) menuPrincipalCursor = (menuPrincipalCursor - 1 + 3) % 3;
        if (bajando) menuPrincipalCursor = (menuPrincipalCursor + 1) % 3;
        if (exit) estadoActual = STAND_BY;
        if (ok) {
          if (menuPrincipalCursor == 0) estadoActual = CONFIRMACION_INICIO;
          if (menuPrincipalCursor == 1) estadoActual = MENU_SELECCION_PROG;
          if (menuPrincipalCursor == 2) { estadoActual = MENU_AJUSTES; menuAjustesCursor = 0; }
        }
        break;
      case CONFIRMACION_INICIO:
        if (ok) {
           etapaActualIndex = 0; tiempoInicioEtapa = millis(); tempInicioEtapa = currentTemperature;
           pidSetpoint = currentTemperature; windowStartTime = millis();
           ultimoCheckWatchdog = millis(); tempEnUltimoCheck = currentTemperature;
           for(int i=0; i<GRAPH_POINTS; i++) tempHistory[i] = 0; graphIdx = 0;
           programaActivoIndex = menuSeleccionProgCursor; // Asegurar que usa el seleccionado
           estadoActual = CALENTANDO;
        }
        if (exit) estadoActual = MENU_PRINCIPAL;
        break;
      case MENU_AJUSTES:
        if (subiendo) menuAjustesCursor = (menuAjustesCursor - 1 + 6) % 6;
        if (bajando) menuAjustesCursor = (menuAjustesCursor + 1) % 6;
        if (exit) estadoActual = MENU_PRINCIPAL;
        if (ok) {
          if (menuAjustesCursor == 0) estadoActual = INFO_WIFI;
          if (menuAjustesCursor == 1) { valorCalibracionEditado = currentTemperature; estadoActual = MENU_CALIBRACION; }
          if (menuAjustesCursor == 2) { menuPIDCursor = 0; estadoActual = MENU_AJUSTES_PID; }
          if (menuAjustesCursor == 3) { estadoActual = MENU_AJUSTES_BRILLO; }
          if (menuAjustesCursor == 4) { sonidoHabilitado = !sonidoHabilitado; guardarConfiguracion(); }
          if (menuAjustesCursor == 5) { borrarWiFiConfig(); }
        }
        break;
      case MENU_AJUSTES_BRILLO:
        if (subiendo) { brilloPantalla += 25; if (brilloPantalla > 255) brilloPantalla = 255; ledcWrite(TFT_LED, brilloPantalla); }
        if (bajando) { brilloPantalla -= 25; if (brilloPantalla < 5) brilloPantalla = 5; ledcWrite(TFT_LED, brilloPantalla); }
        if (ok || exit) { guardarConfiguracion(); estadoActual = MENU_AJUSTES; }
        break;
      case MENU_AJUSTES_PID:
        if (subiendo || bajando) {
          double inc = (menuPIDCursor == 0) ? 1.0 : ((menuPIDCursor == 1) ? 0.05 : 0.1);
          if (menuPIDCursor == 0) Kp += (subiendo ? inc : -inc);
          else if (menuPIDCursor == 1) Ki += (subiendo ? inc : -inc);
          else if (menuPIDCursor == 2) Kd += (subiendo ? inc : -inc);
          if (Kp < 0) Kp = 0; if (Ki < 0) Ki = 0; if (Kd < 0) Kd = 0;
          hornoPID.SetTunings(Kp, Ki, Kd);
        }
        if (ok) { menuPIDCursor = (menuPIDCursor + 1) % 4; if (menuPIDCursor == 3) { guardarConfiguracion(); estadoActual = MENU_AJUSTES; } }
        if (exit) { guardarConfiguracion(); estadoActual = MENU_AJUSTES; }
        break;
      case INFO_WIFI: if (ok || exit) estadoActual = MENU_AJUSTES; break;
      case MENU_CALIBRACION:
        if (subiendo) valorCalibracionEditado += 1.0;
        if (bajando) valorCalibracionEditado -= 1.0;
        if (exit) estadoActual = MENU_AJUSTES;
        if (ok) { 
           if (!isnan(currentTemperature)) { calibracionOffset = valorCalibracionEditado - temperaturaCrudaSimulada; guardarConfiguracion(); }
           estadoActual = MENU_AJUSTES; 
        }
        break;
      case MENU_SELECCION_PROG:
        if (subiendo) menuSeleccionProgCursor = (menuSeleccionProgCursor - 1 + (numProgramasGuardados + 1)) % (numProgramasGuardados + 1);
        if (bajando) menuSeleccionProgCursor = (menuSeleccionProgCursor + 1) % (numProgramasGuardados + 1);
        if (exit) estadoActual = MENU_PRINCIPAL;
        if (ok) {
            if (menuSeleccionProgCursor < numProgramasGuardados) { programaEnEdicionIndex = menuSeleccionProgCursor; configProgCursorVertical = 0; enModoEdicionHorizontal = false; estadoActual = MENU_CONFIG_PROG; }
            else if (numProgramasGuardados < MAX_PROGRAMAS) {
                int n = numProgramasGuardados; sprintf(programas[n].nombre, "NUEVO %d", n+1);
                programas[n].numEtapas = 1; programas[n].etapas[0] = {100, 100, 0};
                numProgramasGuardados++; guardarConfiguracion(); programaEnEdicionIndex = n;
                configProgCursorVertical = 0; enModoEdicionHorizontal = false; estadoActual = MENU_CONFIG_PROG;
            }
        }
        break;
      case MENU_CONFIG_PROG:
        if (enModoEdicionHorizontal) {
          if (ok) configProgCursorHorizontal = (configProgCursorHorizontal + 1) % 3;
          if (exit) enModoEdicionHorizontal = false;
          if (subiendo || bajando) {
            int etIdx = configProgCursorVertical - 1;
            int inc = (configProgCursorHorizontal == 1) ? 5 : ((configProgCursorHorizontal == 0) ? 10 : 1);
            if (configProgCursorHorizontal == 0) { programas[programaEnEdicionIndex].etapas[etIdx].rampa += (subiendo ? inc : -inc); if (programas[programaEnEdicionIndex].etapas[etIdx].rampa < 1) programas[programaEnEdicionIndex].etapas[etIdx].rampa = 1; }
            else if (configProgCursorHorizontal == 1) { programas[programaEnEdicionIndex].etapas[etIdx].temperatura += (subiendo ? inc : -inc); if (programas[programaEnEdicionIndex].etapas[etIdx].temperatura < 25) programas[programaEnEdicionIndex].etapas[etIdx].temperatura = 25; }
            else { programas[programaEnEdicionIndex].etapas[etIdx].tiempo += (subiendo ? inc : -inc); if (programas[programaEnEdicionIndex].etapas[etIdx].tiempo < 0) programas[programaEnEdicionIndex].etapas[etIdx].tiempo = 0; }
          }
        } else {
          int numOpciones = programas[programaEnEdicionIndex].numEtapas + 3;
          if (subiendo) configProgCursorVertical = (configProgCursorVertical - 1 + numOpciones) % numOpciones;
          if (bajando) configProgCursorVertical = (configProgCursorVertical + 1) % numOpciones;
          if (exit) { guardarConfiguracion(); estadoActual = MENU_SELECCION_PROG; }
          if (ok) {
            if (configProgCursorVertical == 0) { charIndexEdicion = 0; estadoActual = EDITANDO_NOMBRE; }
            else if (configProgCursorVertical <= programas[programaEnEdicionIndex].numEtapas) { enModoEdicionHorizontal = true; configProgCursorHorizontal = 0; }
            else if (configProgCursorVertical == programas[programaEnEdicionIndex].numEtapas + 1) {
              if (programas[programaEnEdicionIndex].numEtapas < MAX_ETAPAS) { int i = programas[programaEnEdicionIndex].numEtapas; programas[programaEnEdicionIndex].etapas[i] = {100, 100, 0}; programas[programaEnEdicionIndex].numEtapas++; }
            }
            else if (configProgCursorVertical == programas[programaEnEdicionIndex].numEtapas + 2) {
              if (programas[programaEnEdicionIndex].numEtapas > 1) { programas[programaEnEdicionIndex].numEtapas--; if (configProgCursorVertical > programas[programaEnEdicionIndex].numEtapas) configProgCursorVertical = programas[programaEnEdicionIndex].numEtapas; }
            }
          }
        }
        break;
      case EDITANDO_NOMBRE:
        if (subiendo || bajando) {
          char c = programas[programaEnEdicionIndex].nombre[charIndexEdicion];
          if (subiendo) { c++; if (c > 'Z') c = ' '; if (c == ' '+1) c = 'A'; } else { c--; if (c < ' ') c = 'Z'; if (c == 'A'-1) c = ' '; }
          programas[programaEnEdicionIndex].nombre[charIndexEdicion] = c;
        }
        if (ok) { charIndexEdicion++; if (charIndexEdicion >= MAX_LARGO_NOMBRE - 1) { charIndexEdicion = 0; estadoActual = MENU_CONFIG_PROG; } }
        if (exit) { charIndexEdicion = 0; estadoActual = MENU_CONFIG_PROG; }
        break;
      case FALLO: if (ok || exit) { estadoActual = STAND_BY; actualizarLEDStatus(); } break;
      default: if (exit) estadoActual = STAND_BY; break;
    }
}

void ejecutarCicloDeHorneado() {
  if (estadoActual != CALENTANDO && estadoActual != MANTENIENDO) { digitalWrite(RELAY_PIN, HIGH); return; }
  
  // Watchdog térmico industrial
  if (millis() - ultimoCheckWatchdog > INTERVALO_WATCHDOG) {
    if (digitalRead(RELAY_PIN) == LOW && (currentTemperature < tempEnUltimoCheck + 2.0)) {
       errorMsgStr = "SIN AUMENTO DE TEMP: REVISAR RESISTENCIA"; estadoActual = FALLO; digitalWrite(RELAY_PIN, HIGH); sonarBuzzer(500, 3); actualizarLEDStatus(); return;
    }
    ultimoCheckWatchdog = millis(); tempEnUltimoCheck = currentTemperature;
  }
  
  pidInput = currentTemperature;
  Etapa etapa = programas[programaActivoIndex].etapas[etapaActualIndex];
  unsigned long tSim = (millis() - tiempoInicioEtapa) * SIM_MULTIPLIER;
  
  if (estadoActual == CALENTANDO) {
    pidSetpoint = tempInicioEtapa + (etapa.rampa * (tSim / 3600000.0));
    if (pidSetpoint > etapa.temperatura) pidSetpoint = etapa.temperatura;
    if (currentTemperature >= etapa.temperatura) { estadoActual = MANTENIENDO; tiempoInicioEtapa = millis(); pidSetpoint = etapa.temperatura; guardarEstadoRecuperacion(); actualizarLEDStatus(); }
  } else if (estadoActual == MANTENIENDO) {
    if ((millis() - tiempoInicioEtapa) >= ((unsigned long)etapa.tiempo * 60000 / SIM_MULTIPLIER)) {
      etapaActualIndex++;
      if (etapaActualIndex >= programas[programaActivoIndex].numEtapas) { estadoActual = ENFRIANDO; LittleFS.remove("/recovery.bin"); sonarBuzzer(1000, 1); actualizarLEDStatus(); }
      else { estadoActual = CALENTANDO; tiempoInicioEtapa = millis(); tempInicioEtapa = currentTemperature; guardarEstadoRecuperacion(); actualizarLEDStatus(); }
    }
  }
  
  hornoPID.Compute();
  if (millis() - windowStartTime > windowSize) windowStartTime += windowSize;
  digitalWrite(RELAY_PIN, (pidOutput > (millis() - windowStartTime)) ? LOW : HIGH);
}

void sonarBuzzer(int duracion, int veces) {
  for(int i=0; i<veces; i++) { digitalWrite(BUZZER_PIN, HIGH); delay(duracion); digitalWrite(BUZZER_PIN, LOW); if (i < veces - 1) delay(100); }
}

void sonarClick() { if (sonidoHabilitado) { digitalWrite(BUZZER_PIN, HIGH); delay(20); digitalWrite(BUZZER_PIN, LOW); } }
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

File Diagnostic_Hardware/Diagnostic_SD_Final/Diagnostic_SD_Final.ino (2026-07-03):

/*
 * Diagnostic_SD_Final_V13.ino
 * Pantalla garantizada + Detección de SD
 */

#include <SPI.h>
#include <SD.h>
#include <TFT_eSPI.h>

#define TFT_LED 12
#define SD_CS   33
#define TFT_CS  15

TFT_eSPI tft = TFT_eSPI();

void setup() {
  Serial.begin(115200);
  
  // 1. Backlight ON inmediato
  pinMode(TFT_LED, OUTPUT);
  digitalWrite(TFT_LED, HIGH);
  
  // 2. Inicializar Pantalla
  tft.init();
  tft.setRotation(3);
  tft.fillScreen(TFT_BLACK);
  tft.setTextColor(TFT_WHITE);
  tft.setTextSize(2);
  tft.setCursor(10, 10);
  tft.print("DIAGNOSTICO SD V13.0");
  tft.drawLine(0, 30, 320, 30, TFT_BLUE);

  // 3. Inicializar SD
  tft.setCursor(10, 50);
  tft.print("Buscando tarjeta...");
  delay(1000);

  // Forzar pines CS
  pinMode(TFT_CS, OUTPUT);
  digitalWrite(TFT_CS, HIGH); // Desactivar TFT para el bus

  if (!SD.begin(SD_CS)) {
    tft.setTextColor(TFT_RED);
    tft.setCursor(10, 80);
    tft.print("ERROR: No detectada");
    
    tft.setTextSize(1);
    tft.setTextColor(TFT_YELLOW);
    tft.setCursor(10, 120);
    tft.print("- Revisa cable MISO (GPIO 19)");
    tft.setCursor(10, 140);
    tft.print("- Revisa cable MOSI (GPIO 23)");
    tft.setCursor(10, 160);
    tft.print("- Revisa cable SCK  (GPIO 18)");
    tft.setCursor(10, 180);
    tft.print("- Formato FAT32 (<32GB)");
    Serial.println("SD Falló");
  } else {
    tft.setTextColor(TFT_GREEN);
    tft.setCursor(10, 80);
    tft.print("SD MONTADA: OK!");
    
    uint64_t cardSize = SD.cardSize() / (1024 * 1024);
    tft.setTextColor(TFT_WHITE);
    tft.setTextSize(2);
    tft.setCursor(10, 120);
    tft.printf("Capacidad: %llu MB", cardSize);
    
    // Prueba de archivo
    File f = SD.open("/dac_lab.txt", FILE_WRITE);
    if(f) {
      f.println("Test V13 OK");
      f.close();
      tft.setTextColor(TFT_CYAN);
      tft.setCursor(10, 150);
      tft.print("Escritura: OK");
    }
    Serial.println("SD Funcionando perfectamente");
  }
}

void loop() {}

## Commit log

2026-03-25 Reorganización del proyecto: versiones movidas a carpeta, actualización de FSD.md y README.md con pinout real
2026-03-25 chore: V10.7 release with UI and calibration fixes
    [CC_V10.6.ino]
2026-03-25 docs: Update CHANGELOG.md to mark V10.7 as current
2026-03-25 chore: Fix versioning folder structure and header versions
    [CC_V10.7.ino, CC_V10.8.ino]
2026-03-25 feat: Add buzzer alarms for failure/completion, update version header to V10.8
    [CC_V10.8.ino]
2026-03-26 Release V10.9: New splash screen, PWM brightness control, PID editing, memory meter and UI improvements
2026-04-01 V11.0: Implementar WiFi, Servidor Web y optimización de gráficos con escalado dinámico
2026-04-01 Fix: Corregir error de compilación de namespace FS para WebServer
    [CC_V11.0.ino]
2026-04-01 V11.1: Sonidos de menú y opción de habilitar/deshabilitar sonido
2026-04-02 V11.1: Reajustar posición Y del menú para visibilidad completa
2026-04-02 V12.0: Implementar WiFi Manager Light con Portal Cautivo y Reset WiFi
    [CC_V12.0.ino]
2026-04-02 V12.1: UI Optimizada, Guía visual de configuración WiFi y ajuste de gráfica
2026-04-02 V12.2: Corregir visualización inicial de la pantalla Standby
2026-04-02 Doc: Actualizar README y añadir Checklist de pruebas manuales
2026-04-02 Add hardware design files for custom PCB
    [BOM_Horno_V12.csv]
2026-04-14 V13.0 Industrial: SPI Dual, LED RGB, Hard Reset y mejoras de inmunidad al ruido
    [Drill_NPTH_Through.DRL, Drill_PTH_Through.DRL, Drill_PTH_Through_Via.DRL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]
2026-06-11 docs: Actualizar documentación de pinout y herramientas de diagnóstico
2026-06-11 feat: Actualizar pinout de botones en CC_V13.0.ino
2026-07-02 Implementacion de V14.0: Personality Module, Sincronizacion Dual SD/LittleFS y Feedback RGB/SD en TFT
2026-07-03 Ajustar brillo de LED RGB al 10% en CC_V14.0
2026-07-03 feat: agregar herramientas de diagnóstico de hardware y .gitignore
    - Diagnostic_SD_BruteForce: prueba bruta de SD
    - Diagnostic_SD_Final: versión final de diagnóstico SD
    - Diagnostic_SD_Robust / Robust_Test: pruebas robustez SD
    - Diagnostic_V13: diagnóstico completo V13 hardware
    - Pin_Continuity_Test: verificación de continuidad de pines
    - SD_WakeUp_Test: prueba de wake-up de tarjeta SD
    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
